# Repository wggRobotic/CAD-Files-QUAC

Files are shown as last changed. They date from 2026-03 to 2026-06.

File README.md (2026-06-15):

This repository is going to contain all CAD files related to the QUAC robot project. The files are primarily provided in standard formats such as .STEP, making them compatible with most CAD software and easy to modify if needed.

In addition to 3D-printable components, the repository may also include parts that are not intended for 3D printing (e.g. aluminium profiles, servos and motors, or other external parts). Please refer to the file names and context to distinguish between printable and non-printable elements.

The file QUAC_fullbild shows the complete assembly of the robot and serves as a visual reference for how all components fit together. It can be used as a guide during the assembly process.

The full assembly is illustrated below:

full_build_v6_new

Note that the exact appearance may vary slightly depending on revisions or updates to individual parts.

Further updates, refinements, and additional files may be added over time as the project evolves.

<br><br>

# **Lower_Body-Structure**:

The lower body is mainly built from 20×40 aluminum profiles, providing a strong and robust base structure for the robot.
A custom-shaped 19.2 V NiMH battery pack was specifically designed and 3D-printed to fit efficiently into the available space.
This layout enables a very low center of gravity, which improves overall stability, especially in rough terrain and on obstacle elements.

Lowerbody

## Battery
The robot uses a custom-built NiMH battery pack with 16 FDK HR-4/3FAU NiMH Cell cells, each rated at 1.2 V and 4.5 Ah, resulting in a nominal pack voltage of 19.2 V. Fully charged, the pack reaches nearly 23 V and typically powers the robot for over 90 minutes until the voltage drops to about 19.5 V.

The cells were connected by spot welding, and a 6.8 kΩ B57164-K682-J NTC Thermistor NTC sensor was integrated for charging and temperature monitoring. Power is supplied through a robust 3-pin Molex Mega-Fit Connector connector.

The battery pack was designed to be compact, space-efficient, and evenly balanced to improve driving stability.


## Aluminum parts



The profiles are connected using M5 screws, which are inserted through corner brackets and fastened into trapeze nuts inside the profile grooves. This creates a stable and adjustable connection between the aluminum profiles. The single parts, which are listed below are assembled as shown in the pictures. 

### Long Alu profiles

  The two long aluminium profiles, each measuring 300 × 40 × 20 mm, play a crucial role in ensuring the lateral stability of the overall structure. They act as key reinforcement elements that help prevent deformation and increase rigidity under load. However, to integrate proper cable management, both profiles require manual modification at two designated locations. These sections must be carefully notched out by hand during post-processing to create sufficient space for routing cables. Precision is important here, as the cut-outs need to maintain structural integrity while still allowing clean and functional cable guidance. 
<br><br>

### Short Alu profiles 

The shorter aluminium profiles are used for several specific structural and functional purposes within the assembly. One profile measures 123 × 40 × 20 mm and is installed as a transverse (crosswise) element. It functions as a front bumper component, absorbing impact and providing structural protection. In addition, there are three profiles with dimensions of 83 × 20 × 20 mm. These are also mounted transversely. They serve different roles within the mechanism, with the central one being essential for the installation of the flipper system. Finally, there are four profiles measuring 90 × 20 × 20 mm, which are mounted longitudinally. These elements act as mounting points for the suspension system. They provide the necessary attachment interface for the springs and help distribute mechanical loads evenly throughout the structure.

## Wheels & Rims


<br><br>
Overcoming uneven terrain requires more than just power — it demands exceptional grip, stability, and precise control. To achieve this, we developed a set of custom-designed rims specifically engineered to integrate seamlessly with the [DDSM115 hub motors](https://github.com/wggRobotic/Team-Docs/wiki/4.-Quac-%E2%80%93-All-Terrain-Crawler#part-list) and the selected wheel assemblies. By tailoring the rim geometry to both the motor interface and the tire specifications, we were able to maximize traction, improve load distribution, and ensure reliable performance across challenging surfaces such as gravel, dirt, grass, and rocky terrain.
This custom solution not only enhances the vehicle’s ability to maintain stability on unpredictable ground, but also improves durability and overall driving confidence. The tight integration between the rims, hub motors, and wheels minimizes mechanical play and optimizes torque transfer, allowing the system to respond efficiently even under demanding off-road conditions.

<br><br>

### [Waveshare UGV-Suspension](https://www.waveshare.com/wiki/UGV_Suspension_(A)):
Waveshare_Suspension

The robot uses the Waveshare suspension system to improve terrain adaptability and maintain wheel contact on uneven surfaces.
This passive suspension allows better force distribution across all wheels, increasing traction and stability in rough terrain.

We also experimented with custom springs, extending the suspension travel by approximately 2 cm.
While this improves obstacle handling, especially on uneven terrain, it is still under evaluation as it slightly reduces lateral stability.

<br><br><br><br><br><br>

## Flipper


<br><br>
The flipper mechanism consists of a single servo motor mounted to the central 83 × 20 × 20 mm aluminium profile using a metal clamp. On the other side it has two small steel ball bearings mounted via a 3d-printed part, which function as small additional wheels. Its primary purpose is to temporarily lift the robot by a few centimetres whenever it becomes stuck or obstructed. This allows the robot to free itself from obstacles or uneven terrain and improves overall mobility and reliability during operation.

<br><br>

## Front camera mount

stoßstange2
stoßstange
<br><br>

The front module was originally intended to serve as a bumper. However, the metal bumper was replaced by a custom 3D-printed housing that accommodates an additional permanently mounted camera. Unlike the camera mounted on the robotic arm, this camera remains fixed relative to the chassis and does not move with the arm. This provides a stable external viewpoint that can be used to monitor the arm's position and movement during operation, improving situational awareness and supporting debugging or autonomous tasks. The housing also serves as a mounting platform for additional electronics. An IMU (Inertial Measurement Unit) is mounted on top to provide orientation and motion data, while the servo controller board is installed alongside it to manage the robot's servo-driven mechanisms. By integrating these components into a single compact assembly, the module combines sensing, control, and vision functionality while maintaining a clean and organized design.

# **Upper_Body-Structure**:

The upper body serves as the central platform for all high-level components, including the NVIDIA Jetson Orin Nano Developer Kit, perception sensors such as the Intel RealSense D435 depth camera, and additional electronics.
Structural stability is achieved using 20×20 aluminum profiles, providing a lightweight yet rigid frame.
The design is modular and easily accessible, enabling fast iteration, maintenance, and component replacement during development and competition.
The elevated placement improves sensor field of view and system organization, while still aiming to keep the overall center of mass as low as possible.

Upperbody

<br><br>

## **Manipulator Arm**:

The manipulator arm is primarily composed of 3D-printed components, enabling rapid prototyping and easy customization.
It is actuated using Waveshare ST3215 servos and equipped with a Waveshare gripper for object interaction.
To enable precise perception during manipulation tasks, multiple sensors are mounted directly on the gripper, including depth, thermal, and magnetic field sensing.
This setup allows the robot to detect and interact with objects in close proximity in a targeted and efficient manner.

ARM

### Camera mount
Kamera_Halterung v2
Kamera_Halterung v2 1

The camera mount is a small 3d-printed plate that is necessary to atatch both the Intelrealsense and the thermal camera to the gripper. The camera is off-centre because the Intel RealSense has its RGB camera on the left. Therefore, slightly off-centring the camera gives us a better view of the gripper and a more centred view of our surroundings from the robot's perspective. 
<br><br>

### Gripper
The custom gripper design was inspired by Festo’s bionic [Fin Ray gripper](https://www.youtube.com/watch?v=JAyPTIIpFiA). It utilizes a triangular structure based on the geometry of fish fins, which provides passive compliance. This flexibility allows the gripper to conform seamlessly to the contours of an object. Furthermore, the inherent flexing mechanism protects the servo motors from damage, preventing mechanical strain if the gripper over-closes.

Gripper-A-Fisch v16

FischGripperBacke5FinnenFlach v7

Through many iterations, we learned which geometric facts matter by constructing the gripper. It is important that the cross-connections are perpendicular to the angle bisector of the tip. Also, you can change the stiffness of the gripper with the number of cross-connections. We tried at first 7 cross-connections, which was too rigid. So we decreased them through many iterations and finished with the iteration with just 5 cross-connections, which seemed to be a nice compromise.

<br><br>

### Arm mount
Verankerung_rechts v1
arm_mount
<br><br>

The arm mount is a custom 3D-printed component that serves as the primary interface between the robotic arm and the crawler chassis. It securely attaches the arm to the robot's structure while ensuring proper alignment and load transfer during operation. To improve cable management, the mount incorporates a dedicated routing notch that allows the motor cables to pass through the component in a controlled manner. This protects the cables from excessive bending, reduces the risk of snagging, and contributes to a cleaner overall assembly. By combining structural support and cable routing in a single part, the arm mount simplifies the design and improves reliability.

## Aluminum parts
### Profiles

The upper body frame is constructed from aluminium profiles and reinforced with corner brackets to ensure a lightweight yet stable structure.
The two long horizontal profiles measure 300 × 20 × 20 mm and form the main supporting structure of the upper body. Mounted onto them are several vertical profiles measuring 60 × 20 × 20 mm, which provide additional rigidity and serve as mounting points for other components.
Corner brackets are installed between the horizontal and vertical elements to strengthen the joints, improve stiffness, and maintain precise alignment throughout the frame.
<br><br>

### Base plate
base_plate
Zeichnung_Aluplatte_WGG

The baseplate was custom-manufactured by Dehn in cooperation with our team based on our technical design specifications. It is made from a 165 × 300 × 5 mm aluminium plate and forms the central structural foundation of the robot.
The plate includes precisely machined mounting holes for attaching structural components as well as dedicated openings for cable routing, enabling clean and organized wiring throughout the system. Due to its thickness and material choice, the baseplate provides excellent rigidity and stability while still maintaining a relatively low weight. The exact dimensions and hole positions can be taken from the technical drawing.

### Bottom cover plates
bottom_cover_plates
To achieve a cleaner and more professional appearance, black acrylic cover plates were added to conceal the PCB and wiring. Integrated cable openings allow the wires to be neatly routed to the individual components, improving cable management while maintaining easy access for maintenance.
The covers are mounted using trapeze nuts inside the aluminum profiles together with countersunk screws, creating a secure and flush finish. Additionally, the design is divided into three separate sections, allowing modular access to the front, rear, and the centrally mounted Jetson module for easier maintenance and system integration.

### Top cover plate
Top_cover_plate
top_cover_plate_topdown
	
The top cover functions as a protective roof structure mounted on top of the short aluminum profiles. It is securely fastened using M5 screws inserted into self-cut threads.
Besides protecting the internal components, the cover also serves as the main mounting platform for the rear camera, LiDAR sensor, kill switch, and the LiDAR hub together with its mounting system. Positioning these components at a higher point on the robot significantly improves the field of view and sensor performance. It‘s especially important for the LiDAR, which is on 7mm ring elevation, and the camera for accurate mapping, environment detection, and autonomous navigation.
To ensure durability during operation, the LiDAR sensor is additionally protected by a welded wire cage that shields it from impacts and external damage without obstructing its scanning capabilities

### Side cover
side_cover
HexagonAbdeckung v3

The side cover is a custom-designed and 3D-printed panel mounted to the sides of the robot. Its primary purpose is to protect the internal components from external impacts and debris while maintaining sufficient airflow through the chassis. A honeycomb-shaped cut-out pattern has been integrated into the design to maximize ventilation and improve cooling performance. This allows air to circulate freely through the robot, helping to prevent heat buildup around the electronics and other components. The cover is attached to the aluminium frame using 5 × 5 mm permanent magnets, allowing it to be installed and removed quickly without the need for tools. In addition to its protective function, the side cover improves the overall appearance of the robot and conceals internal components such as cables, electronics, and mounting hardware. This results in a cleaner, more professional design while keeping the interior organized and protected.

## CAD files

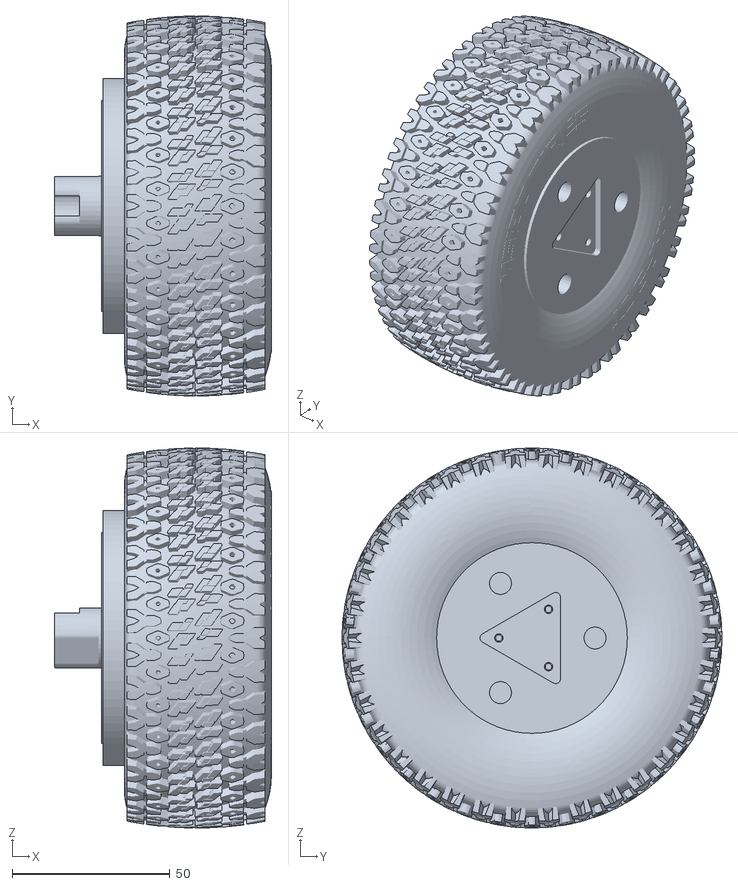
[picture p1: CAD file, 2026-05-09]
QUAC_v6_Wheel.stl
69.0 x 120.6 x 120.6

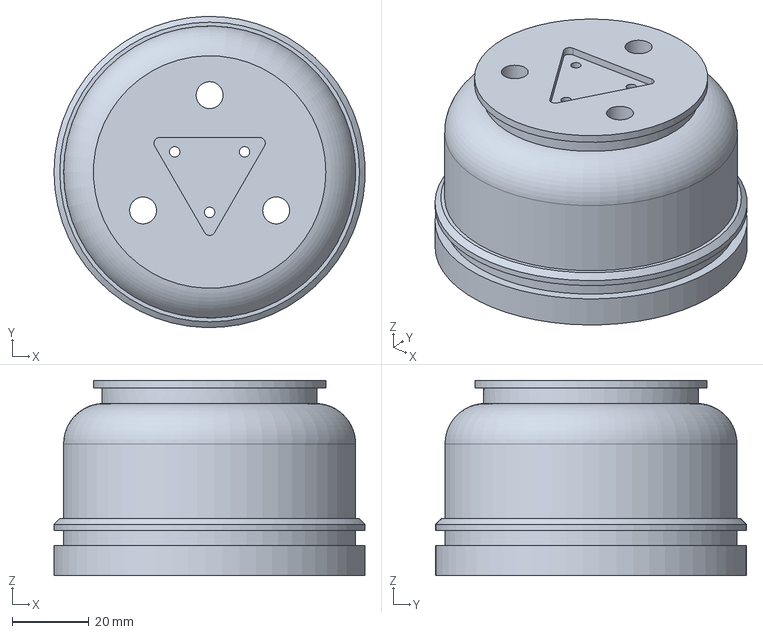
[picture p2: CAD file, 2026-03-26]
Felge_3_0.step
80.9 x 81.0 x 50.8 mm

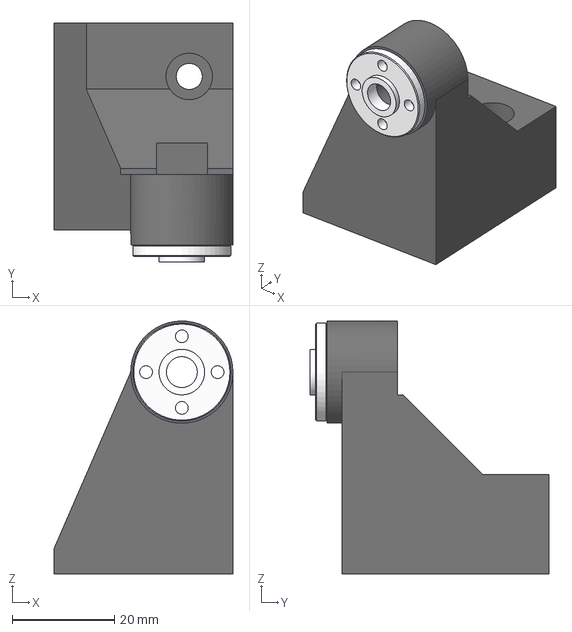
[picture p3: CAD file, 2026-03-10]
Verankerung_links_neu v8.step
35.0 x 46.8 x 49.5 mm

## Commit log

2026-03-10 Update README to clarify CAD-files content
2026-03-26 Enhance README with robot structure details
    Added detailed descriptions of the robot's lower body structure, upper body structure, and manipulator arm, including materials, design considerations, and functionality.
2026-05-28 Refactor README.md for formatting and clarity
    Updated section headers to use consistent capitalization and improved descriptions for aluminum parts and base plate.
2026-05-28 Add image for bottom cover plates in README
    Added an image for bottom cover plates in the README.
2026-05-28 Enhance README with top cover plate images and details
    Added images and improved descriptions for the top cover plate and Lidarhub mount in the README.
2026-06-10 Fix link to DDSM115 hub motors in README
    Updated link to DDSM115 hub motors in the README.
2026-06-10 Replace assembly image in README
    Updated image link for full assembly illustration.
2026-06-12 Add front camera mount section to README
    Added a section about the front camera mount, detailing its purpose and integration with the robot's design.
